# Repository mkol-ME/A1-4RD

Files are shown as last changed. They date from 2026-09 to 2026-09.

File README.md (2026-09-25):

# A1-4RD — "Alfred"




A 3D-printed desk companion with a moving jaw and a voice, written in the manner of an old-fashioned
butler: dry, warm, terse, and genuinely useful. Not a smart speaker.

Everything runs locally. A laptop (later a Raspberry Pi inside the printed body) is the face: microphone,
speaker, wake word. A headless Ubuntu box on the LAN is the brain: speech recognition, memory, web lookup,
the language model and his voice. Nothing is sent to a hosted service.

> **The character is the project. Everything else is plumbing.**

## What I built, and what I learned

I built a voice assistant with a fixed personality that runs entirely on my own hardware: speech detection
and wake word on a laptop, and Whisper, a 26-billion-parameter language model, long-term memory, web and
weather lookup and a custom synthesized voice on a home server. That server runs on a secondhand datacenter
GPU I had to reflash and coax into a consumer motherboard. Through measurement rather than guesswork, I got
a spoken reply's first sound down to about 1.15 seconds, and a web-searched answer from 7.1 to 3.5 seconds.
The biggest lesson was that intuition is unreliable with language models. Adding rules to the prompt made
the character worse three separate times. My first test suite passed while the real failures went
undetected, because its questions had leaked into the training examples. Two confident theories about why
he rambled both turned out wrong. So I built a held-out evaluation that checks its own contamination, and
changed things only when a number moved. I also learned to put boundaries in code rather than instructions:
anything that reaches the prompt will eventually be said out loud, so access to memory has to be enforced in
the database query itself.

## The physical build

The body is fully modelled in CAD; it has not been printed or assembled yet.

<p align="center">
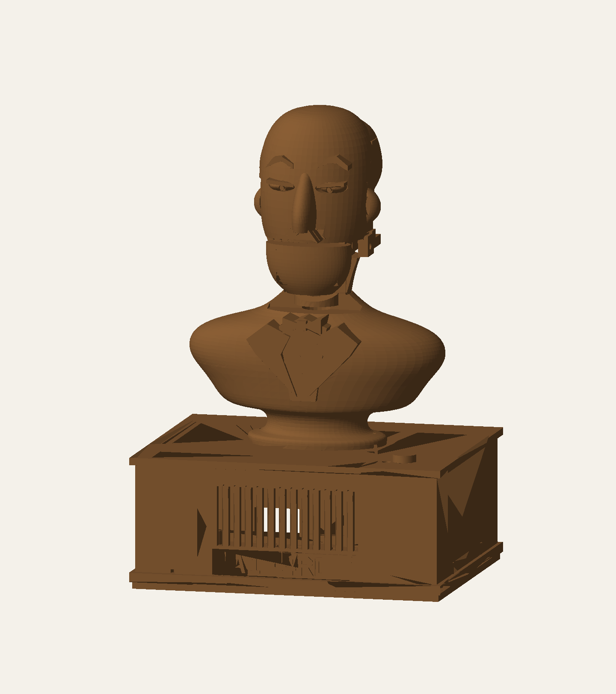
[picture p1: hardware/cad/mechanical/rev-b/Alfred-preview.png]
Rendered CAD model of the Alfred bust on its speaker plinth
  
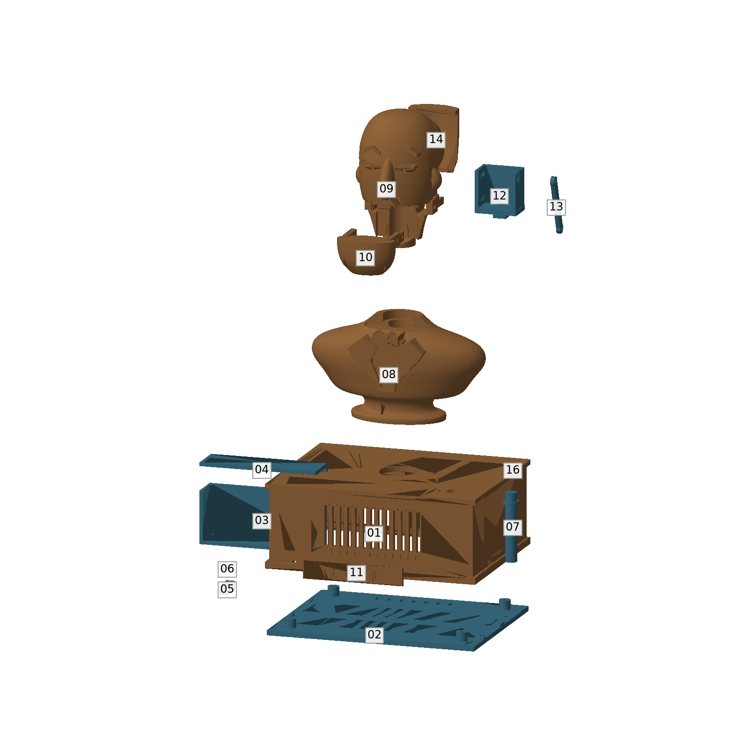
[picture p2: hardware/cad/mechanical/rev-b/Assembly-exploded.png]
Exploded view of the sixteen printed parts
  
</p>

- **Printed body** ([`hardware/cad/mechanical/rev-b`](hardware/cad/mechanical/rev-b)): sixteen parts as STEP
  solids and millimetre STL, 202 mm tall. The chin is a separate part, driven by a servo through a drive
  link, so the jaw can move while he speaks.
- **Electronics layout** ([`hardware/cad/mechanical/modules-rev-a`](hardware/cad/mechanical/modules-rev-a)):
  a tray and fit models for off-the-shelf boards — Raspberry Pi, I²S microphone, amplifier, servo driver and
  USB-C power.
- **Custom carrier PCB** ([`hardware/cad/pcb/rev-e`](hardware/cad/pcb/rev-e)): a four-layer KiCad board for a
  Pi Zero 2 W, an ICS-43434 microphone, a MAX98357A amplifier and the jaw servo, with a latching power-fault
  cutoff. Gerbers, drill files, BOM and DRC/ERC reports are included; revisions C to E are kept. Not yet
  fabricated.

The STEP files open in SolidWorks, Fusion or FreeCAD. [`hardware/cad/README.md`](hardware/cad/README.md) maps
every revision.

---

## Contents

- [The physical build](#the-physical-build)
- [How a spoken turn works](#how-a-spoken-turn-works)
- [Hardware](#hardware)
- [Repository layout](#repository-layout)
- [Talking to Alfred](#talking-to-alfred)
- [The server](#the-server)
- [Performance](#performance)
- [Testing](#testing)
- [Status and roadmap](#status-and-roadmap)
- [Further reading](#further-reading)

---

## How a spoken turn works

```text
 LAPTOP (client/)                               SERVER (brain/, over an SSH tunnel)
 ─────────────────                              ───────────────────────────────────────────────
 microphone, 16 kHz
   → speech detection against the room's
     measured noise floor
   → at 0.20 s of silence, send audio ────────→ Whisper small.en on the GTX 1060
   → at 0.40 s, end the turn — or wait up to
     1.0 s if the words so far trail off
   → wake word / attention window
   → text ────────────────────────────────────→ voice server
                                                  → tool gate: does this need a lookup?
                                                  → decider: search memory / search web
                                                    (SearXNG, Wikipedia) / sports scores
                                                    (ESPN) / news (Google News) / remember
                                                    weather goes to Open-Meteo instead
                                                  → gemma4 26B on the MI50 via Ollama
                                                  → cut the stream into whole sentences
                                                  → Alfred's distilled Piper voice (CPU)
 speaker (WASAPI) ←──── one WAV per sentence ─── ← streamed as NDJSON
```

The pieces are deliberately separable:

| Layer | Files | Decides |
|---|---|---|
| **Character** | `persona/` (private; `.example` stand-ins here), `brain/prompts.py` | how he behaves |
| **Knowledge** | `brain/memory.py`, `brain/memory_tools.py`, `brain/web.py`, `brain/weather.py`, `brain/sports.py`, `brain/news.py`, `brain/markets.py` | what evidence he sees |
| **Transport** | `brain/voice_server.py`, `brain/whisper_server.py`, SSH | how text and audio move |
| **Embodiment** | `client/listen.py`, `client/talk.py`, later the servos | how he is present in the room |

A better voice cannot fix a bad answer, and a longer prompt cannot replace memory, so each layer is
debugged on its own.

---

## Hardware

**Server** (headless Ubuntu 24.04; setup and operation in [docs/server.md](docs/server.md))

| Part | Role |
|---|---|
| i7-8700 · 48 GB DDR4 · MSI MPG Z390 Gaming Plus | host |
| **AMD Radeon Instinct MI50 32 GB** | the language model (Ollama, Vulkan backend) |
| **NVIDIA GTX 1060 6 GB** | Whisper |
| 500 GB NVMe · 3×2 TB RAID 5 · 1.5 TB | OS and models · Alfred's memory database · spare |

The MI50 is a secondhand datacenter card. Getting it working in a consumer board took a VBIOS reflash,
*Above 4G Decoding* in the BIOS and `pci=realloc` on the kernel command line. It has no fan of its own, so a
server fan is driven from the card's temperature by [`ops/fan`](ops/fan). Two driver settings keep the whole
model in video memory; without them half of it silently spilled into system RAM, at 4 tokens a second
instead of 40 ([why each setting is there](docs/server.md#ollama-settings)).

**Client:** any Windows laptop with a microphone. Later: a Raspberry Pi in the printed body, with a servo jaw
and a neck servo — see [The physical build](#the-physical-build).

---

## Repository layout

```text
A1-4RD/
├── brain/                    runs on the server
│   ├── alfred.py             model choice, prompt assembly, streaming; also a terminal chat client
│   ├── memory.py             SQLite memory: recent conversation, facts, semantic search
│   ├── memory_tools.py       the tool decider and its tools (memory, web, facts)
│   ├── web.py                Wikipedia + SearXNG lookup, run concurrently
│   ├── sports.py             live scores, results and fixtures from ESPN
│   ├── news.py               headlines from Google News
│   ├── markets.py            live prediction-market odds from Polymarket
│   ├── machine.py            the server's own temperatures, fan, power, VRAM, RAID and disks
│   ├── weather.py            live forecast from Open-Meteo, not search snippets
│   ├── media.py              "play…" / "find videos of…" requests and spoken titles
│   ├── media_server.py       YouTube search, audio stream, chapters and captions (own venv: yt-dlp, PyAV)
│   ├── guru.py               The MMA Guru's take on a fight, from his breakdown videos
│   ├── voice_server.py       one spoken turn end to end, streamed sentence by sentence
│   ├── whisper_server.py     resident Whisper, so no model load per utterance
│   ├── audio_archive.py      every utterance kept on the array with its transcript, under a size cap
│   ├── youtube.py            what a named YouTube channel has posted, from its real upload list
│   ├── spoken.py             text rules for what is said aloud, such as which voice reads a sentence
│   ├── prompts.py            loads the private wording, or the .example stand-ins
│   └── whisper_transcribe.py one-off file transcription
├── persona/
│   ├── alfred.example.md     stand-in for alfred.md (who he is), which is kept private
│   ├── examples.example.md   stand-in for examples.md (how he talks)
│   └── prompts.example.json  stand-in for prompts.json (the instructions sent with each turn)
├── client/                   runs on the laptop
│   ├── listen.py             speak to him: wake word, attention window, early transcription
│   ├── talk.py               type to him, hear him answer; also the audio player
│   ├── music.py              plays YouTube audio; pause, stop, volume, ducking under his voice
│   └── launcher/             builds Alfred.exe, a double-click launcher
├── scripts/                  server launch scripts, and a scratch copy of the voice server for testing
├── voice-training/           how his voice was made: auditions, RVC, distillation into Piper
├── tests/                    unit tests for memory, tool gate and the listening loop
├── ops/                      server setup, version-controlled
│   ├── fan/                  MI50 fan curve service + interactive installer
│   ├── reboot/               idle-only 3 a.m. reboot every third night
│   ├── ollama/               Ollama settings and boot-time model preload
│   ├── services/             start SearXNG, Whisper and the voice server at boot
│   └── remote-access/        key-only SSH and Tailscale
├── requirements/             pinned environments (client TTS, Whisper, RVC, Qwen-TTS)
├── hardware/                 CAD (STEP/STL), KiCad PCB and bring-up notes for the body
└── docs/                     running the server, and reaching it
```

---

## Talking to Alfred

- Say **"Alfred, …"** to start. He then stays attentive for three minutes without needing his name.
  **"That'll be all"** dismisses him.
- Say his name while he is talking and he stops, so you can cut in.
- **"Play …"** asks whether you want Spotify or YouTube, then plays it through his speaker. **"Find videos
  of …"** reads out the top results. While music plays, **"Alfred, pause / resume / stop / louder / quieter"** works, and the
  music drops whenever he talks.
- Ask about the weather, last night's game, the news, or something you told him last week. He decides
  on his own when a question needs a lookup.
- Typing works too: the same conversation and memory, without the audio.

Running the client and the server is covered in [docs/server.md](docs/server.md).

---

## Performance

Measured 2026-09-16, from the end of speech to Alfred's first sound, with real audio through the whole
pipeline:

| Turn | Before the MI50 work | Now |
|---|---|---|
| Plain conversation ("why do my prints warp") | 1.5 s | **≈ 1.15 s** |
| Needs the tool decider ("what should I have for dinner") | 4.2 s | **≈ 1.6 s** |
| Memory lookup ("what did I tell you about…") | 4.5 s | **≈ 1.9 s** |
| Web search, real answer (holding line at ≈ 1.0 s) | 7.1 s | **≈ 3.5 s** |

**Model choice.** Candidates run on the MI50 with Alfred's real prompt:

| Model | First sentence | Speed | Character eval |
|---|---|---|---|
| **gemma4:26b Q8** (in use) | **0.43 s** | 41 tok/s | **75/78** |
| gemma4:31b | 1.61 s | 15 tok/s | 77/78 |
| qwen3.6:35b-a3b | 1.35 s | 54 tok/s | 75/78 |
| qwen3.8:27b | 5.50 s | 17 tok/s | — |
| qwen3.5:9b (previous) | 1.77 s | 63 tok/s | 67/78 |

The Qwen 3.x models re-read the whole persona on every turn; Gemma reuses the cached prefix, which is most of
the gap. `gemma4:31b` is the alternative if character ever matters more than speed — one line in
`brain/alfred.py`.

---

## Testing

The unit tests cover memory, the tool gate, the listening loop (segmentation, wake word, unfinished
sentences), the spoken-reply rules, the voice EQ and each lookup's parsing. They need no GPU or model, and
[run on every push](https://github.com/mkol-ME/A1-4RD/actions/workflows/tests.yml):

```bash
pip install numpy scipy sounddevice
python -m unittest discover -s tests
```

The character, conversation and routing evaluations are built on the private persona and real
conversations, so they are kept out of this repository along with it.

---

## Status and roadmap

**Done**
- The persona, and the full voice pipeline: ears, memory, lookups, voice
- MI50 bring-up and latency work; services that start at boot; remote access over Tailscale
- Live weather, sports, news and web search; spoken corrections
- Music from YouTube or Spotify, ducked under his voice; cutting in by saying his name
- A typed client sharing the same conversation and memory
- Optional tools loaded from outside the repository, which can report back when a long job finishes
- The printed body and the carrier PCB, designed in CAD

**Next**
- Recognising who is speaking, with separate memory per person (enforced in SQL, never in the prompt)
- Small character faults — through example curation, not more rules
- A bench prototype of the electronics ([plan](hardware/bringup-plan.md))

**Later:** the Raspberry Pi client inside the printed body, with the servo jaw and neck; timers and alarms
that still ring when the network is down.

---

## Further reading

- [docs/server.md](docs/server.md) — running the client and the server
- [docs/SSH.md](docs/SSH.md) — reaching the server
- [hardware/](hardware) — the physical build

## License

The code is released under the [MIT License](LICENSE). The Adafruit board files in
[`hardware/cad/mechanical/modules-rev-a/source/board-sources`](hardware/cad/mechanical/modules-rev-a/source/board-sources)
keep their own CC BY-SA licence.

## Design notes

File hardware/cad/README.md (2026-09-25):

# Alfred CAD archive

These are the complete generated CAD deliverable folders for the Alfred physical prototype. Each revision is kept intact so its own README, checks, source files, and exports stay together. They are **design snapshots**, not proof of a built or qualified device.

| Folder | Contents | Status |
| --- | --- | --- |
| `mechanical/rev-a/` | Initial bust and enclosure; STEP, STL | Superseded by rev B |
| `mechanical/rev-b/` | Revised bust, jaw, enclosure; STEP, STL | Latest exterior baseline |
| `mechanical/module-fit-review/` | Fit review and next steps | Reference notes |
| `mechanical/modules-rev-a/` | Revised tray and fit models for off-the-shelf Pi/audio/power modules; STEP, STL, CadQuery source | Latest module-based prototype geometry; use with the rev B exterior parts named in its README |
| `pcb/rev-c/` | KiCad carrier project and fabrication exports | Superseded by rev D |
| `pcb/rev-d/` | KiCad carrier project and fabrication exports | Superseded by rev E |
| `pcb/rev-e/` | KiCad carrier project and fabrication exports | Latest custom-PCB candidate; unbuilt and purchasing deferred |

## Starting points

- For the printed body and currently proposed breakout-module prototype, start with `mechanical/rev-b/README.md` and `mechanical/modules-rev-a/README.md`.
- For the custom PCB design, start with `pcb/rev-e/README.md` and its power-acceptance and validation notes. Do not send its Gerbers for fabrication without the remaining physical checks.
- The repository's `hardware/v1-electronics-bom.pdf` is a separate early bench-shopping list. It is not a purchasing BOM for the module package or PCB rev E.

Large STEP and STL files are stored with Git LFS. The native SolidWorks files are kept offline; the STEP exports open in SolidWorks. Clone with Git LFS enabled to receive the actual models rather than pointer files.

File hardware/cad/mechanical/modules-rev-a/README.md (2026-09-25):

# Alfred — module prototype A

13 September 2026. A mechanical layout and fit-test package for the Pi Zero 2 W / local-server architecture. **Bench qualification remains required; this is not a tested appliance or a PCB fabrication release.**

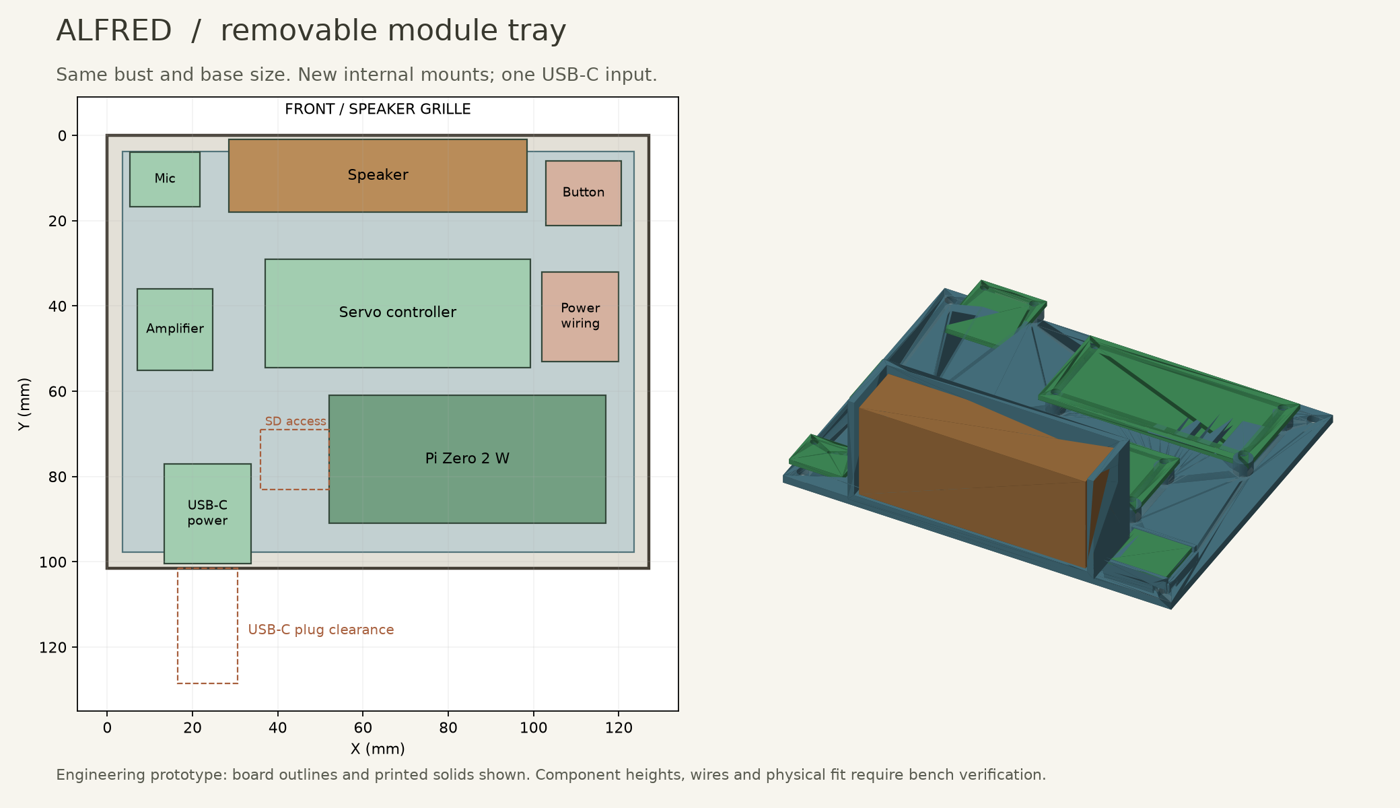
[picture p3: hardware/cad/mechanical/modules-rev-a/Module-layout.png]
Module layout


## What changed

The finished bust exterior, overall size and existing jaw linkage are retained. The custom carrier PCB is replaced by an assembled microphone board, amplifier board, servo pulse controller and USB-C power-input board on a printed tray. A small hand-wired power distribution assembly and button perfboard are still required. Some header and wire soldering is unavoidable.

New or revised printed parts:

| File in CAD/ | Change |
|---|---|
| 01_Plinth_modules | Existing rear power opening extended left to X=15.5 and upward to Z=21.5. Front and overall envelope unchanged. |
| 03_Speaker_mount_modules | Adds a lead clearance notch behind the speaker. |
| 07_Button_stem_modules | Shortens the lower end to Z=22.1 for a switch actuator at Z=21.9. |
| 17_Electronics_tray | Uses the four existing base supports; separate board mounts and microphone acoustic extension. |
| 18_Switch_carrier | Supports a 17.78 x 15.24 x 1.6 mm piece of perfboard beneath the original button. |

Unchanged parts are included as STEP/STL. The original SolidWorks files are kept offline, unchanged; Revision B's STEP exports carry the same geometry. New parts are STEP solids, printable STL and regenerable Python/CadQuery geometry, **not native SolidWorks feature trees**. Import the assembly STEP into SolidWorks for inspection or further work. Reference envelopes are named separately and must not be printed as hardware.

## Selected electronics

| Qty | Item | Purpose / constraint |
|---:|---|---|
| 1 | Raspberry Pi Zero 2 W | Existing Python/SSH audio client. Use a header fitted on the component side. |
| 1 | Adafruit 6049, ICS-43434 breakout | Microphone; bottom acoustic port faces the printed duct. |
| 1 | Adafruit 3006, MAX98357A mono amplifier | Drives the enclosed speaker. |
| 1 | Adafruit 815, PCA9685 servo controller | Produces stable servo pulses independently of Linux scheduling. PCB Rev C source used for mounting. |
| 1 | Adafruit 5807, HUSB238 power breakout | One USB-C input, fixed **5 V / 3 A request**. See Wiring.md before connecting. |
| 1 | Raspberry Pi official 27 W USB-C supply, appropriate regional version | Previously selected supply; validate its actual 5 V contract and loaded output with the HUSB238. Do not infer 5 A operation from the supply label. |
| 1 | Adafruit 3351, enclosed 4-ohm 3 W speaker | Nominal body fits the existing cradle; verify actual lead exit and tabs. |
| 1 | FEETECH FS90 positional servo | Original jaw mechanism. FS90R continuous-rotation is unsuitable. |
| 1 | Omron B3F-1000 momentary switch | On separate perfboard, centered under the existing button. |
| 1 each | Littelfuse 025102.5MXL and 02511.25MXL | 2.5 A Pi/audio branch fuse and 1.25 A motor branch fuse; verify startup/inrush on bench. |
| 1 | 470–1000 uF, 10 V radial electrolytic, body at most 8 mm diameter x 20 mm high | At PCA9685 V+ / GND capacitor footprint; observe polarity. Capacity is a bench starting value, not proof of transient immunity. |
| 1 each | 1 kohm and 10 kohm resistors, 0.125 W or greater | OE pull-up and amplifier SD pull-down. |
| 1 | 10 kohm resistor | Button pull-up to 3.3 V. |
| 1 | 32 GB or larger microSD and reader | Lite OS, client software and configuration. |
| As needed | Perfboard, 22 AWG stranded power wire, 26–28 AWG signal wire, 2.54 mm headers/shunt, heat-shrink, connectors, strain relief | See Wiring.md. No powered breadboard rails for the motor branch. |

The parts above define the design, not a current shopping cart. Price/availability and exact cable/header SKUs will be checked in the purchasing step. The controller adds cost but avoids a servo software-timing problem and preserves future channels. No extra computer is needed inside Alfred.

## Assembly sequence

1. Print the existing fit coupon (15) first. Use it for bores and a servo body trial. Then trial-print the new tray, switch carrier and shortened stem in ordinary PETG before cosmetic filament.
2. Check the real servo before committing to the head assembly. The old cradle has an approximately 22.6 mm clear width between rails, while the supplier gives dimensions up to 23.2 mm body length and 23 mm case/gear height in its drawing. Orientation matters. The old CAD does not conclusively establish the shaft position with the real servo and horn. Do not force it or file the servo case; adjust the cradle after a measured fit. The servo axis must remain parallel to X at Y=58, Z=176 for the existing link.
3. Place the unchanged duct and lid on the bottom cover. Fit the tray at Z=9 using four M3 screws. M3 x 8 is a starting length; washer/head stack and screw penetration must be checked. The modeled screw-head envelope is diameter 6.2 x 2.5 mm above tray top. Use heads within that envelope.
4. Seal the tray's acoustic bore to the existing duct lid with a thin perimeter seal. Fit a compressible annular gasket into the 0.2 mm recess at the top of the microphone riser. Its central opening must remain clear. Mic board underside is Z=16. Clip solder tails below the microphone header to at most 1.5 mm and inspect clearance over the nearby M3 head.
5. Install board fasteners with insulating washers. Tray holes are 2.2 mm: use M2 screws and nuts, including for the Pi's larger holes. Mic/Pi/amp/PCA seat Z=16; power board seat Z=14.5. M2 x 12 for the former and M2 x 10 for power are starting lengths. Fit nuts before placing the tray where access would become difficult; test screw tip clearance above the floor.
6. Fit the switch centered at X=111.75,Y=13.55 on the small perfboard, with board underside Z=16. Carrier side rails support the board; retain with removable tape at its edges. Attach the carrier feet to the tray after fitting tray screws. Verify 0.2 mm initial actuator gap and free return before bonding the cap.
7. Fit the speaker with thin foam. Orient the cable through the revised notch. The listed speaker nominal envelope leaves 2 mm total slack in each pocket dimension before padding. Retain the original lid with a light strap or removable tape.
8. Secure the insulated power harness in the reserved X=102..120,Y=32..53,Z=13..37 volume. Keep solder joints off printed plastic using insulating supports. Secure wiring with adhesive cable anchors; no loose assemblies in the cavity. Keep the Pi's antenna end and ventilation free of wire bundles.
9. Bench-test before closing the base. The Pi SD card is serviced by removing the bottom module; the former rear SD opening remains a vent/service opening, not an aligned card slot. The new power module is screwed down near the rear opening; confirm the actual USB-C plug fits the modeled 14 x 6 mm section and can fully seat.
10. Route the servo cable through the torso with a service loop behind the moving jaw. Retain the existing jaw pivot, 35.114 mm link and 8 mm horn radius. Begin calibration with the link detached. Attach only after real closed/open pulse limits have been established.

## What the checks establish

The package includes fresh STL integrity checks and BRep intersection checks of the printed assembly against module board outlines, component/service envelopes and tray screw heads. The envelopes reserve space; they are not certified manufacturer 3D models. Wires can bend outside their nominal reserved spaces unless secured.

**The actual servo, horn, cable deformation, print shrinkage, thermal behavior, acoustics and power transients are not validated by these checks.** Existing jaw-motion results remain a printed-geometry-only reference. No physical Pi has been booted or measured in this task.

Compared with the custom PCB, this prototype has basic branch fuses and servo output disabling; it does **not** reproduce the PCB's undervoltage latch, active inrush limiting or regeneration clamp. It is for supervised bring-up. Measure the power behavior before extended assembled use; a fuse alone does not stop a stalled servo promptly or prevent a brownout.

See Wiring.md for connections and Bring-up.md for test order. Custom PCB Rev E remains unfinished and should not be ordered.

## Sources

- [Raspberry Pi Zero 2 W](https://www.raspberrypi.com/products/raspberry-pi-zero-2-w/)
- [Microphone PCB files](https://github.com/adafruit/Adafruit-I2S-MEMS-Microphone-Breakout-PCB)
- [Amplifier PCB files](https://github.com/adafruit/Adafruit-MAX98357-I2S-Amp-Breakout)
- [Servo-controller PCB files](https://github.com/adafruit/Adafruit-16-Channel-PWM-Servo-Driver-PCB)
- [Power-module PCB files](https://github.com/adafruit/Adafruit-USB-Type-C-Power-Delivery-Dummy-Breakout-PCB)
- [HUSB238 jumper instructions](https://learn.adafruit.com/adafruit-husb238-usb-type-c-power-delivery-breakout/pinouts)
- [Speaker dimensions](https://www.adafruit.com/product/3351)
- [FS90 supplier drawing](https://www.pololu.com/file/0J1435/FS90-specs.pdf)
- [Littelfuse 251 datasheet](https://www.littelfuse.com/assetdocs/littelfuse-fuse-251-253-datasheet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)

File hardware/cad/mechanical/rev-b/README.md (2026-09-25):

# A1-4RD / Alfred — printable prototype, revision B

STEP parts and a reference assembly, plus millimetre STL exports. The native SolidWorks files are kept offline.
Designed from alfred.jpg and the routed carrier PCB mechanical interface from the earlier task.
The face has solid eyeballs, iris relief, pupils, half-lowered lids, eyebrows, a long nose, ears and a moustache. The chin is a separate moving part. This is a stylized CAD interpretation of the reference, not a scanned likeness.

## Scale and coordinates

Overall nominal height 202 mm (7.95 inches), including base. Plinth footprint 137 x 111.6 mm, with a small additional projection at the front lettering. Main base wall 3 mm. Internal chamber 127 x 101.6 x 50.8 mm, measured above the floor at global Z=3 mm. Global X goes right, Y goes back, Z goes up. Internal front-left floor corner is (0,0,3).

Carrier PCB 120 x 94 x 1.6 mm. PCB front-left XY=(3.5,3.8). Underside Z=9, top Z=10.6. Four M3 pilot supports at (7.5,7.8), (119.5,7.8), (7.5,93.8), (119.5,93.8). Pi support hardware remains M2.5 and mounts on the PCB, not the enclosure floor.

The PCB, Pi, commercial servo, servo horn, speaker and fasteners are NOT included as detailed component models. Purchased-part compatibility is based on the preceding PCB interface and listed nominal dimensions. Measure the actual header stack, switch, servo shaft location and speaker before the final print.

## Files and parts

| Part | Material | Assembly / print note |
|---|---|---|
| 01_Plinth | Bronze PLA | Speaker front, USB/SD rear; print top face on bed, cavity upward, inspect supports around grille |
| 02_Bottom_cover | PETG | PCB supports; print floor on bed |
| 03_Speaker_mount | PETG | Padded 72 x 19 x 32 mm pocket; bond to inner front wall at model position; no supports through PCB |
| 04_Speaker_lid | PETG | Removable roof; retain with removable tape or a light strap |
| 05_Microphone_duct | PETG | Print open channel upward, clean bore, bond to bottom cover |
| 06_Microphone_duct_lid | PETG | 0.5 mm roof; use 0.1 mm layers; 0.2 mm thin gasket seat around PCB mic bore |
| 07_Button_stem | PETG | Insert from underneath BEFORE bonding cap |
| 08_Torso | Bronze PLA | Hollow wiring space, jacket and bow tie; support as needed; M3 attachment from inside plinth |
| 09_Alfred_head | Bronze PLA | Solid eyes and face; rear service opening; print with supports kept away from eye details where possible |
| 10_Moving_jaw | Bronze PLA or PETG | Separate chin, axle cheeks and rearward drive arm; ream bores |
| 11_Name_plaque | Bronze PLA | A1-4RD lettering raised 0.8 mm; place flat back on bed; bond to front |
| 12_Servo_cradle | PETG | Strap mounting with an M2 base screw; confirm actual FS90 body/shaft position |
| 13_Drive_link | PETG | Print flat; 35.114 mm pivot-center distance; M2 clearances |
| 14_Rear_cover | Bronze PLA | Removable prototype cover; retain with narrow removable tape around rear seam |
| 15_Fit_coupon | PETG | First print: servo body sample and 3.2 mm bores |
| 16_Button_cap | Bronze PLA | Bond onto installed stem; keep glue out of guide |

Use one of each. Assembly contains the 15 installed printed components; the coupon is separate. The assembly is a fixed positional reference, not a mated motion simulation. The linkage is positioned at the closed-jaw reference.

All part files share assembly coordinates. In Bambu Studio import individual STLs as separate objects and use Lay on Face / Drop to Bed; do not print their floating assembly Z coordinates. No printer-specific G-code is supplied.

## Jaw mechanism

Use a 3 mm metal axle, approximately 50 mm long, trimmed to the actual head width and retained at both ends. Printed main axle bores are 3.2 mm in the head and 3.3 mm in the jaw. Ream to a free-running fit; do not force a screw thread through a bearing surface.

Reference jaw pivot: (Y,Z)=(52,143). The jaw drive point is 10 mm behind the pivot, at (62,143) when closed. Reference servo shaft: (58,176), axis parallel to X. Use an 8 mm horn radius and the 35.114 mm link. The rod occupies X=79.5..81.9. Use M2 screws, washers/spacers and locknuts to maintain free pivots. Keep the supplied servo spline/horn; no printed spline is provided.

| Jaw opening | Reference crank angle |
|---:|---:|
| 0 degrees | 180.000 degrees |
| 5 | 173.513 |
| 10 | 166.483 |
| 15 | 158.776 |
| 20 | 150.181 |

These are geometric angles in the YZ plane, NOT servo PWM commands. Calibrate the horn's center and actual shaft position before connecting the linkage. The bracket allows strap mounting rather than relying on unverified tab holes. If the purchased shaft cannot be placed at the reference coordinate, modify the bracket/link before operation. Start with a small travel range and limit normal operation to 0..20 degrees. Do not drive the servo into a stop.

The head includes a BRep clearance feature calculated from sampled jaw positions and a 2% enlargement of the jaw around its pivot. Earlier sketches/features remain in the native file, but this final clearance body does not automatically regenerate from upstream changes: recalculate it after changing jaw geometry or pivot placement.

## Hardware and fit

- Four M3 screws for the PCB, four M3 screws through the bottom cover, and two M3 screws from inside the base into the torso. Pilot holes are 2.6 mm; verify self-tapping fit on scrap. Select lengths to avoid bottoming or piercing the shell; PCB screws typically M3 x 6 with insulating washers, cover M3 x 8, torso M3 x 8 subject to washer thickness.
- Head has a 20 mm spigot and torso a 20.6 mm socket. Lightly bond after wiring/fit confirmation; rear cover permits servo access.
- Servo cradle uses an M2 screw into a 1.7 mm pilot, with a recessed head, and narrow cable ties through the rail slots.
- Speaker: Adafruit 4445 nominal 70 x 31 x 17 mm enclosed body, padded with thin foam. Mounting is by cradle, not its unverified screw pattern. Keep factory enclosure intact.
- The microphone duct must be sealed to the PCB underside around its 0.5 mm acoustic bore. Use a thin compressible gasket; keep adhesive, dust and filament out of the acoustic path.
- Button stem is based on a nominal 4.3 mm switch height above PCB top: 0.2 mm initial clearance and about 0.45 mm cap travel. Verify the actual B3F-1000 actuator height/travel and adjust stem length before bonding cap.
- Keep the Pi antenna area free of metal hardware and cable bundles. Provide a service loop in the neck.
- Rear USB opening: global X 23.5..43.5, Z 6.5..18.5. SD access: X 81.5..115.5, Z 19.5..31. Allow cable and card withdrawal space behind the figure.

## Bambu P1 print starting point

Use a 0.4 mm nozzle. Start with the appropriate Generic PLA / Generic PETG profile, then tune to the filament manufacturer. Decorative head and jaw: 0.12–0.16 mm layers; base/torso: 0.20 mm; 4 walls and 15–20% infill as a starting point. Mechanism: 4–5 walls; link 100% infill. Slow outer walls for the face and lettering. Inspect support contact and bore cleanup in the slicer. The thin microphone lid should be printed separately at 0.1 mm layers.

Bronze PLA is appropriate for the cosmetic shell; PETG is preferred for internal supports. Validate enclosure temperature with the real electronics running before long unattended use. ABS is unnecessary for this first prototype.

## Filament sourcing — checked 6 September 2026

1. [Polymaker Panchroma Metallic Bronze PLA, 1.75 mm, 1 kg](https://shop.polymaker.com/products/metallic-pla?variant=43595097407545): $24.99, selected Bronze variant available when checked. Manufacturer calls for at least a 0.4 mm nozzle, 190–230 C nozzle and 25–60 C bed. Bronze appearance comes from a decorative metallic effect; no plating needed.
2. [Polymaker PETG, Black / New Formula, 1.75 mm, 1 kg](https://shop.polymaker.com/products/petg?variant=45079221108793): $18.99, selected variant available when checked.

Two-spool subtotal $43.98 before tax/shipping; no purchase has been made. One bronze spool and one PETG spool are a practical starting purchase including test prints. If you already have PETG, buy only bronze. Availability can change.

Material references: [Polymaker metallic PLA](https://shop.polymaker.com/products/metallic-pla), [Prusa PETG guide](https://help.prusa3d.com/article/petg_2059), [FS90 specifications](https://www.pololu.com/product/2818/specs).

## Release status

This is an unbuilt prototype. Geometric checks cover the modeled printed parts; they do not establish purchased hardware fit, print tolerance, acoustic performance, motor calibration or thermal performance. See the validation JSON files for exact checks performed. Print the coupon and mechanism first, then the cosmetic pieces.

## Reinforced head and assembly guide

The final head has connected 4 mm side rails, upper/lower crossmembers, reinforced axle bearings and a thicker rear neck root. Use six walls on the head. See Alfred-assembly-guide.pdf for the exploded schematic, linkage dimensions and numbered assembly instructions.

Validation: all 16 STL meshes checked for watertightness, winding and connected components (mesh-validation.json); all native part bodies passed kernel checks. No static printed-part interferences were detected. Jaw/link motion was sampled at each integer degree from 0 through 20 against the modeled head, torso, cradle and rear cover; no collisions were detected at those samples. Purchased components were not included in that clearance check.

## Revision B: classical bust silhouette and BTAS facial details

The torso now has broad upper shoulders, a tapered chest and an integral short oval socle inspired by the supplied classical bust photograph. Alfred retains a formal shirt, pointed tuxedo lapels, bow tie and shirt studs. The original head/socket position, 202 mm overall height, base attachment and PCB enclosure dimensions are preserved. The torso includes a continuous 18 x 16 mm wiring passage through the pedestal.

The head revision trims the long ears into compact lobed ears with shallow inner recesses, adds raised receding side-hair volumes, and sharpens the pointed moustache. The bald crown, solid eyes and reinforced jaw frame remain. These facial features are integral prints.

Reference: original user Alfred BTAS image, supplemented by [The World's Finest Alfred reference gallery](https://dcanimated.com/batribute/batribute-characters/batribute-characters-alfred-index2/).

The new torso has a front-neck relief for the moving chin. The rear neck and socket floor retain the head support; route and secure the neck service loop behind the moving chin.

## Reinforced head and assembly guide

The final head has connected 4 mm side rails, upper/lower crossmembers, reinforced axle bearings and a thicker rear neck root. Use six walls on the head. See Alfred-assembly-guide.pdf for the exploded schematic, linkage dimensions and numbered assembly instructions.

Validation: all 16 STL meshes checked for watertightness, winding and connected components (mesh-validation.json); all native part bodies passed kernel checks. No static printed-part interferences were detected. Jaw/link motion was sampled at each integer degree from 0 through 20 against the modeled head, torso, cradle and rear cover; no collisions were detected at those samples. Purchased components were not included in that clearance check.

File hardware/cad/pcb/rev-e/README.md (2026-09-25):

# Alfred carrier - revision E

Native KiCad 10 project for Pi Zero 2 W, ICS-43434 microphone, MAX98357A amplifier and one FS90 servo. Revision E replaces D for the next prototype evaluation. Purchasing is deferred.

- R107: verified 32.0k 0.1% part, with recalculated supervisor thresholds.
- R101: Pi/audio current limit lowered from about3.33A to2.02A nominal.
- C101:10nF; slower Pi/audio startup reduces nominal reservoir charging surge from0.94A to0.44A.
- External requirements now include the Pi, microSD, stencil/assembly and enclosure/linkage.

The supported design target is <=1.65A Pi/audio and <=0.80A servo; the earlier4.1A operating allocation is withdrawn. This is a deliberate reduction in supported load, not proof that all power-margin concerns are resolved. Read Power-acceptance.md. It includes source-voltage/path-loss criteria and tests that still require built hardware. The hardware latch still prevents restart after a detected fault until a deliberate new command edge.

Open Alfred.kicad_pro. Use the current BOM, Gerbers, assembly instructions and drawings together. Validation.txt records the completed CAD and offline checks. No physical board or target audio software has been tested; prototype power qualification is still open. Do not describe this release as production-qualified.

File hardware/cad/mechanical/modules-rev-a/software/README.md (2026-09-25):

# Pi client hardware setup — module prototype A

The server continues to perform transcription, language generation and voice synthesis. No server model changes are needed.

The supplied audio overlay and smoke test are adapted from the previous hardware package. They target the Raspberry Pi voiceHAT codec/machine interface at 48 kHz, stereo, signed 32-bit little-endian audio. **The overlay has not been compiled or boot-tested on a physical Pi in this task.** Verify the installed kernel provides the required drivers and symbols.

1. Install Raspberry Pi OS Lite. Install `device-tree-compiler` and `alsa-utils` using its package manager.
2. Confirm the kernel has `snd_soc_googlevoicehat_codec` and `snd_soc_rpi_simple_soundcard`, either modules or built in.
3. Run `sh build-overlay.sh`. If successful, copy `alfred-audio.dtbo` into the active boot overlays directory, normally `/boot/firmware/overlays/`. Back up the boot configuration before editing it.
4. Use this configuration, removing conflicting audio overlays:

```ini
dtparam=audio=off
dtparam=i2c_arm=on
dtoverlay=alfred-audio
gpio=22=op,dh
```

GPIO17 is owned by the audio driver for amplifier SD. GPIO22 is PCA9685 OE, HIGH=disabled. Do not install the former GPIO12 PWM overlay or the former GPIO22 LOW-at-boot setting.

5. Reboot and inspect `arecord -l` and `aplay -l`. Run the smoke test using its `--help` instructions and the actual card name. It plays a quiet tone and captures the mic; listen to the recorded file and inspect logs, not just the exit code.
6. Configure the existing `listen.py`/`talk.py` audio devices. Native hardware format is 48 kHz stereo S32_LE; use tested conversion to the client's expected format. Mic data is on the left channel. Do not assume the default audio device or channel mapping is correct.
7. Add PCA9685 support using a maintained I2C library. Initialize OE HIGH, initialize at 50 Hz with unused channels off, set the actual calibrated channel-0 pulse, then enable OE. Keep the identity button on GPIO27. A completed servo integration into the Alfred client is a separate target-hardware step; this package does not silently modify the working client.

The old PCB supply-good/fault pins and hardware arm latch do not exist in this module prototype. Read ../Wiring.md before using any old servo code.

Kernel references reviewed in the prior design:

- https://raw.githubusercontent.com/raspberrypi/linux/rpi-6.12.y/sound/soc/bcm/googlevoicehat-codec.c
- https://raw.githubusercontent.com/raspberrypi/linux/rpi-6.12.y/sound/soc/bcm/rpi-simple-soundcard.c
- https://raw.githubusercontent.com/raspberrypi/linux/rpi-6.12.y/arch/arm/boot/dts/overlays/googlevoicehat-soundcard-overlay.dts

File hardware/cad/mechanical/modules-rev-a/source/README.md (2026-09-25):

# Regenerating the geometry

Install requirements.txt into a separate Python environment, then run build_module_cad.py. It uses the source STEP geometry and saved manufacturer PCB snapshots and regenerates this package's CAD, assembly, placement and clearance outputs. Back up manual changes first. New geometry is parameterized in the script; imported original parts remain STEP solids.

Manufacturer board files and attribution/license texts are retained under board-sources. Original Adafruit board designs are credited to Adafruit Industries and their respective designers; see each supplied README and license. New enclosure changes were made for the Alfred project. Reference blocks are simplified fit envelopes, not manufacturer-certified component models.

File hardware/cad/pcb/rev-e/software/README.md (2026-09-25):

# Alfred audio and jaw bring-up

This package adds a concrete audio integration path. It is **source-reviewed, not tested on a physical Alfred or compiled on this Windows host**. Use Raspberry Pi OS with the Raspberry Pi kernel and the existing voiceHAT codec/machine modules. Review was against `rpi-6.12.y`; verify compatibility for the image you install.

The voiceHAT codec supports simultaneous 48 kHz stereo S32_LE capture/playback and controls an amplifier enable GPIO. The companion machine driver selects standard I2S and derives a 64-bit frame for 32-bit samples. Those interfaces match Alfred's intended clocks and data wiring. The included overlay changes amplifier enable to **GPIO17**. Do not use the unmodified stock overlay, which drives GPIO16 instead.

## Setup on the Pi

1. Install `device-tree-compiler`, `alsa-utils` and Python 3 using the Pi's package manager. Confirm `modinfo snd_soc_googlevoicehat_codec` and `modinfo snd_soc_rpi_simple_soundcard` find the modules; built-in drivers may instead appear in the kernel configuration. If neither modules nor built-ins exist, use a supported Raspberry Pi kernel before proceeding.
2. Run `sh build-overlay.sh` in this directory. Stop if dtc reports errors. Copy the resulting `alfred-audio.dtbo` to `/boot/firmware/overlays/` (older installations use `/boot/overlays/`). Keep a backup of the boot configuration before editing it.
3. Add the following to the active boot configuration (`/boot/firmware/config.txt` on current Raspberry Pi OS):

```ini
dtparam=audio=off
dtoverlay=alfred-audio
gpio=22=op,dl
# GPIO12 uses hardware PWM0, separate from the I2S pins.
dtoverlay=pwm,pin=12,func=4
```

Remove conflicting I2S audio overlays and do not enable PWM analog audio. Reboot manually after reviewing the file. No installation or reboot is performed by the supplied build script.

4. Use `arecord -l` and `aplay -l` to identify the same voiceHAT card in both directions. Use its actual ALSA ID; do not assume it is card 0. The kernel card name contains `googlevoicehat` because the existing driver is reused.
5. With the servo disconnected and hardware voltages checked, run `python3 audio-smoke-test.py --device hw:YOUR_CARD_ID,0`. This intentionally emits a quiet test tone and records two short local WAV files. Avoid other audio clients during the test. The script refuses to overwrite its output folder; choose a new `--output` for each run.

## Application contract

- Use 48,000 Hz, two 32-bit slots, S32_LE. Expected LRCLK is 48 kHz and BCLK 3.072 MHz.
- Capture contains the microphone in the **left** channel. Extract that channel for recognition; the right channel is not a second microphone. The mic has 24 useful bits within the 32-bit slot.
- Playback also uses the **left** channel. Duplicate mono speech into both slots or explicitly place it on the left.
- Start at -12 dBFS or lower for speech and raise only after testing. Revision E's 9 dB hardware gain can approach the speaker's 3 W rating at full scale, but clean output depends on supply and load. The smoke test uses -30 dBFS.
- The kernel owns GPIO17. Do not claim it in the Alfred application at the same time.
- Add playback-reference acoustic echo cancellation for listening while speaking. Full duplex alone does not suppress the loudspeaker or servo noise.
- Test continuous capture while repeatedly starting/stopping playback, then the reverse. Run a 30-minute combined test with Wi-Fi and supervised jaw movement; log ALSA errors, `vcgencmd get_throttled`, and minimum measured Pi-header voltage.

## Jaw control contract

GPIO22 requests servo power; GPIO25 reports supply-good; GPIO27 reports active-low servo fault. GPIO12 is PWM0. Keep request low on startup and shutdown. Prepare a 50 Hz PWM waveform at a calibrated neutral pulse before requesting power. Use hardware PWM through the kernel; do not use a PCM-timed servo library while audio uses I2S.

Revision E has a hardware arm latch. First drive GPIO22 LOW. Require GPIO25 supply-good HIGH for at least 100 ms and GPIO22 LOW for at least 10 ms before a deliberate GPIO22 rising edge. A request issued while supply-good is LOW will not arm later when the rail recovers. The supervisor also applies about 107 ms nominal recovery qualification. Check the fault input after the servo rail has completed its approximately 12 ms startup ramp. Clear GPIO22 immediately if supply-good falls or a powered-servo fault appears, and require a deliberate retry. After a detected undervoltage fault, hardware remains disarmed even if GPIO22 stayed HIGH. Deliberately clear it LOW and repeat qualification only after investigating the fault. Do not auto-retry a jam in a tight loop. On application exit, clear the power request before releasing PWM/GPIO ownership.

Start with the linkage detached. A 1500 us pulse is a conventional starting point, not a guarantee of Alfred's safe jaw position. Measure and store the real closed/open limits; never assume the full 500-2500 us range is safe. No jaw movement script is included because the mechanical limits have not been supplied.

## Sources

- [Raspberry Pi voiceHAT codec](https://raw.githubusercontent.com/raspberrypi/linux/rpi-6.12.y/sound/soc/bcm/googlevoicehat-codec.c)
- [Raspberry Pi machine driver](https://raw.githubusercontent.com/raspberrypi/linux/rpi-6.12.y/sound/soc/bcm/rpi-simple-soundcard.c)
- [Raspberry Pi voiceHAT overlay](https://raw.githubusercontent.com/raspberrypi/linux/rpi-6.12.y/arch/arm/boot/dts/overlays/googlevoicehat-soundcard-overlay.dts)

The DTS uses the existing GPL kernel interfaces and carries a GPL-2.0-only identifier. It identifies the compatible interface; it does not claim Alfred is a Google-manufactured board.

## Offline logic check

Run `python3 validate-hardware-logic.py` from any directory to repeat the latch truth-table sequence checks and static threshold calculations. This reads the package design-data.json. It neither accesses GPIO nor substitutes for physical fault injection.

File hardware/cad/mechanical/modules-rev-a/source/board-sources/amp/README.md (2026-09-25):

## Adafruit MAX98357 I2S Amp Breakout PCB
<a href="http://www.adafruit.com/products/3006"><br/>
Click here to purchase one from the Adafruit shop</a>
<a href="http://www.adafruit.com/products/6513"><br/>
Click here to purchase one from the Adafruit shop</a>

The all in one digital audio amp breakout board that works incredibly well with the Raspberry Pi! If you're looking for an easy and low cost way to get you digital sound files bumpin' then the MAX98357 I2S Amp Breakout is for you. It takes standard I2S digital audio input and, not only decodes it into analog, but also amplifies it directly into a speaker. Perfect for adding compact amplified sound, it takes 2 breakouts (I2S DAC + Amp) and combines them into one.

I2S (not to be confused with I2C) in a digital sound protocol that is used on circuit boards to pass audio data around. Many high end chips and processors manage all of the audio in digital I2S format. Then, to input or output data, three or four pins are used (data in, data out, bit clock and left-right channel select). Usually, for audio devices, there's a DAC chip that will take I2S in and convert it to analog that can drive a headphone.

This small amplifier is surprisingly powerful - able to deliver 3.2 Watts of power into a 4 ohm impedance speaker (5V power @ 10% THD). Inside the miniature chip is a class D controller, able to run from 2.7V-5.5VDC. Since the amp is a class D, it's incredibly efficient - making it perfect for portable and battery-powered projects. It has built in thermal and over-current protection but we could barely tell it got hot.

PCB files for the Adafruit MAX98357 I2S Amp Breakouts
- https://www.adafruit.com/product/3006
- https://www.adafruit.com/product/6513

### License

Adafruit invests time and resources providing this open source design, please support Adafruit and open-source hardware by purchasing products from [Adafruit](https://www.adafruit.com)!

All text above must be included in any redistribution

Designed by Limor Fried/Ladyada for Adafruit Industries.
Creative Commons Attribution/Share-Alike, all text above must be included in any redistribution. 
See license.txt for additional information.

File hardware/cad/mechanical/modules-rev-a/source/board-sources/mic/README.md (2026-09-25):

## Adafruit I2S MEMS Microphone Breakout - ICS-43434 PCB

<a href="http://www.adafruit.com/products/6049"><br/>
Click here to purchase one from the Adafruit shop</a>

PCB files for the Adafruit I2S MEMS Microphone Breakout - ICS-43434. 

Format is EagleCAD schematic and board layout
* https://www.adafruit.com/product/6049

### Description

Listen to this good news - we now have a breakout board for a super tiny ICS43434 I2S MEMS microphone. Just like 'classic' electret microphones, MEMS mics can detect sound and convert it to voltage, but they're way smaller and thinner. This microphone doesn't even have analog out, it's purely digital. The I2S is a small, low-cost MEMS mic with a range of about 50Hz - 15KHz, good for all general audio recording/detection. The chip has a built in low-pass filter that cuts frequencies above 24KHz.

For many microcontrollers, adding audio input is easy with one of our analog microphone breakouts. But as you get to bigger and better microcontrollers and microcomputers, you'll find that you don't always have an analog input, or maybe you want to avoid the noise that can seep in with an analog mic system. Once you get past 8-bit micros, you will often find an I2S peripheral that can take digital audio data in! That's where this  I2S Microphone Breakout featuring the TDK ICS43434 comes in.

Instead of an analog output, there are three digital pins: Clock, Data, and Left-Right (Word Select) Clock. When connected to your microcontroller/computer, the 'I2S Controller' will drive the clock and word-select pins at a high frequency and read out the data from the microphone. No analog conversion required!

The microphone is a single mono element. You can select whether you want it on the Left or Right channel by connecting the Select pin to power or ground. If you need stereo, pick up two microphones! You can set them up to be stereo by sharing the Clock, WS, and Data lines but having one with Select to ground, and one with Select to high voltage. No firmware or driver configuration is required, you'll get 24-bit output instantly.

This I2S MEMS microphone is bottom ported, so make sure you have the hole in the bottom facing out towards the sounds you want to read. It's a 1.6-3.6V max device only, so it is not for use with 5V logic (it's really unlikely you'd have a 5V-logic device with I2S anyway). Many beginner microcontroller boards don't have I2S, so ensure it's a supported interface before you try to wire it up! This microphone is best used with Cortex M-series chips like the SAMD21 or SAMD51, ESP32, RP2040 or RP2350, or single-board computers like the Raspberry Pi.

[For code, libraries, wiring examples, CAD files, Fritzing, and more, check out the guide!](https://learn.adafruit.com/adafruit-i2s-mems-microphone-breakout/)

### License

Adafruit invests time and resources providing this open source design, please support Adafruit and open-source hardware by purchasing products from [Adafruit](https://www.adafruit.com)!

Designed by Limor Fried/Ladyada for Adafruit Industries.

Creative Commons Attribution/Share-Alike, all text above must be included in any redistribution. 
See license.txt for additional details.

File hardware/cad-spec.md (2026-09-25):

# Explaining the A1-4RD base to an AI: the CAD side

## First, be clear about what you are asking for

An AI cannot hand you a good STEP file. It has no geometric kernel, no view of
your model, and no way to check a fit. What it *is* good at is everything
upstream and downstream of the geometry:

| Ask it for this | Not this |
|---|---|
| A written design spec you then model from | "Generate the enclosure" |
| Kinematics: linkage lengths, servo throw → jaw angle | An assembly file |
| Print orientation, overhang, tolerance, and shrink advice | A sliced G-code file |
| A parametric script (build123d / CadQuery / OpenSCAD) | A parametric Fusion file |
| A review of a design you describe back to it | A review of a screenshot it half-reads |

You are fluent in CAD. The leverage is in the **spec** and the **mechanism math**,
not in it drawing boxes. So the deliverable you should ask for is a dimensioned
specification and a decisions log — something you can model from in an hour —
plus a parametric script only if you want a throwaway first body to check
proportions.

## The spec skeleton — fill this in, then hand it over

The reason CAD requests to an AI come back useless is almost always that one of
these seven is missing. Fill each one, in this order.

**1. Origin and datums.** Where is (0,0,0), which way is +Z, what face sits on
the desk. Every dimension afterwards references this. Say it explicitly or you
will get answers in three different coordinate frames.

**2. Envelope.** Outer footprint, total height, and the internal volume left
after wall thickness. State the wall thickness you intend and the material.

**3. Interfaces — the actual content.** For each, position, orientation, and
tolerance:
- PCB: outline, mounting hole coordinates and diameter, standoff height, which
  edge the USB-C connector exits and how much clearance it needs to the wall.
- Servos: pocket dimensions for the body, screw hole spacing, output shaft
  position and axis, and how much sweep the horn needs unobstructed.
- Speaker: diameter, depth, sealed or ported chamber, grille pattern and open
  area, standoff from the wall.
- Microphone: the port hole diameter and the gap between the PCB mic and the
  outer surface. This one has a right answer acoustically and a wrong one.
- Button: cap diameter, travel, panel thickness at that spot, how it retains.
- Cable routing from base to head, and strain relief at both ends.
- SD card and USB access without disassembly, or an explicit decision that you
  accept disassembly.

**4. Assembly strategy.** How it comes apart, how many pieces, what fastens to
what — heat-set inserts, self-tapping screws, snap fit, magnets. Say which, and
the hole diameters that go with it. Also say what has to be serviceable versus
what can be permanent.

**5. Print constraints.** Printer, nozzle, layer height, material, and the
orientation you intend for each part. Then the rules that follow: max unsupported
overhang angle, minimum feature size, whether supports are allowed, and which
surfaces are cosmetic. State your clearance convention explicitly — e.g. 0.2 mm
for sliding fits, 0.1 mm for press fits, holes drawn 0.2 mm oversize — because
otherwise you will get generic advice you already know.

**6. Aesthetic intent.** This is the part people leave out and it is the whole
project. Say it in plain language: he is a classic English butler at six inches — dry,
warm, formal. The base should read as a butler's stand, not a gadget. "A1-4RD"
is a visual pun that goes on the base as a nameplate. Screws should not be
visible from the front. Give the AI the reference and the feeling; it will push
back on details that fight it.

**7. What is already fixed.** The jaw is driven from a precomputed angle curve,
so it moves continuously through speech rather than snapping open and shut —
which means the linkage needs smooth travel over a modest range, not a binary
open/closed action. The head nods. The figure is six inches. Those are settled.

## The kinematics ask — do this one separately

The jaw is the only real mechanism, and it is worth a dedicated conversation.
Give the AI: the jaw pivot location, the desired open and closed jaw angles, the
servo's usable rotation, the servo mounting position, and the space available for
a linkage. Ask it for link lengths and attachment points that map servo angle to
jaw angle smoothly, plus the resulting non-linearity across the range so you can
compensate in software if it matters. That is a solvable geometry problem and it
will do it well. Ask it to "design the jaw" and it will write you a paragraph.

## Copy-paste prompt

---

I am designing the 3D-printed base for a six-inch desk companion figure called
A1-4RD ("Alfred") — a butler character, dry and formal, not
a consumer gadget. The base houses a Raspberry Pi Zero 2 W on a custom carrier
PCB, a speaker, a microphone, a button, and the wiring up to two servos in the
figure (jaw and neck nod). I am fluent in CAD and printing, so I do not need
modeling instruction — I need a rigorous specification and the mechanism math.

I will give you the parameters below. Your job:

1. Ask me for anything missing before you produce anything. Do not fill gaps with
   assumptions.
2. Produce a **dimensioned specification** I can model from directly: every
   feature located against a stated origin, with tolerances and the reasoning
   behind each number. Not prose descriptions of features — coordinates and
   dimensions.
3. Produce a **decisions log**: each choice, the alternative you rejected, and
   why. I want to be able to argue with your reasoning.
4. Flag every place where my constraints conflict with each other, and every
   place a decision depends on something I have not measured yet.
5. Where a number is acoustically or mechanically load-bearing — the mic port,
   the speaker chamber, the servo pocket fit — say so and give me the rule, not
   just the value.

Be blunt about problems. If something I have specified will not print, will not
fit, or will sound bad, say so plainly and give me the fix.

My parameters:

[paste the seven-section spec here]

---

## Sequencing note

Do the PCB architecture stage first. Its stage-4 mechanical interface sheet —
board outline, hole coordinates, connector positions, component keep-out heights
— is exactly the input section 3 of this spec needs. Designing the enclosure
around a board that has not settled means doing it twice.

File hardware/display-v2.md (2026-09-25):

# V2 base display: preliminary interface

Goal: add an approximately four-inch screen to the base that shows Alfred's
spoken reply as readable text. Placement, touch support, and exact module are
still open. The initial working assumption is a screen on the front face that
shows captions without touch controls.

## Connection and data path

- Keep the Pi Zero 2 W for now. It exposes mini HDMI, not a DSI display port.
  A four-inch HDMI LCD can use the Pi's video output while the GPIO header stays
  available for I2S audio, servos, button, and indicator.
- Supply the LCD from a protected 5 V branch and include its backlight draw in
  the measured power budget. Do not power it through a thin Pi jumper wire in
  the final assembly. Route a short mini-HDMI cable with connector clearance,
  bend radius, and strain relief inside the base.
- `brain/voice_server.py` already sends `{"text": ..., "audio": ...}` for each
  voiced sentence. `client/talk.py` reads these frames and queues the audio.
  The Pi client can hand each `text` value to a local caption view as the audio
  is queued. This gives sentence-level captions. Word-by-word highlighting
  would need timing data that the current server does not send.
- The caption view should clear when a new turn begins, wrap and scroll long
  replies, show the most recent sentence in large type, and turn the backlight
  down when idle. Treat any text from private memory as visible to everyone
  who can see the base.

## Mechanical implications

- Four inches is a diagonal, not a panel footprint. Select a real module and
  use its panel, PCB, mounting-hole, connector, and cable drawings before
  fixing the base diameter or front angle. A landscape display will likely
  make the base wider than the six-inch figure.
- Keep the display/bezel replaceable. A removable front panel lets a first
  body be built without a screen while preserving a V2 upgrade path.
- Keep the speaker outlet and mic port away from the LCD cavity. The screen
  panel should not become the speaker baffle or block the acoustic path.

## Prototype test

Before committing to a screen or larger base, connect a small HDMI monitor to
the Pi and render captions from the existing sentence frames. Check text size
at desk viewing distance, first-caption timing, scrolling during long replies,
and simultaneous audio playback. Then bench-test the chosen four-inch module
for its actual current and connector clearance.

One example to evaluate is the [Waveshare 4inch HDMI LCD](https://www.waveshare.com/wiki/4inch_HDMI_LCD),
an 800×480-class IPS module (native panel orientation is 480×800) that requires
an HDMI cable on the Zero 2 W. Its resistive touch function uses additional
GPIO/SPI resources, so leave touch disconnected if the screen only displays
captions. This is a candidate, not a selected part.

Sources: [Pi Zero 2 W interfaces](https://www.raspberrypi.com/products/raspberry-pi-zero-2-w/),
[Waveshare module guide](https://www.waveshare.com/wiki/4inch_HDMI_LCD).

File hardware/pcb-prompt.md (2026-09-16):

# Prompt: A1-4RD base PCB

Paste everything below the line into the other AI. Fill the four `<<< >>>` blanks
first — everything else is already decided.

---

You are an electronics design engineer helping me design a small custom PCB. I
have designed PCBs before at a hobby level but this is the most integrated board
I have attempted, so I want you to be actively skeptical of my choices and tell
me where I am about to make a beginner mistake. Do not be agreeable.

## What the board is for

I am building a six-inch 3D-printed desk companion called A1-4RD ("Alfred") — a
character, not a smart speaker. It has a moving jaw and a nodding head, listens
for a wake word, and talks. All heavy compute (speech-to-text, LLM, text-to-
speech) happens on a separate headless Linux server on my LAN. The board in the
figure's **base** is a thin client only: it captures audio, plays audio, drives
two servos, reads one button, and talks to the server over Wi-Fi.

This board replaces a laptop that currently does that job over an SSH tunnel, so
the software side is already working and is not in scope. I need the hardware.

## Fixed decisions — do not relitigate these

- **Compute is a Raspberry Pi Zero 2 W**, used as a module. My board is the
  carrier; the Pi plugs into it via the 2x20 0.1" header. I want the Pi
  removable (SD card access, and I do not want to solder a $15 board down).
- **Audio is I2S in and out**, not USB, not analog. Digital MEMS mic in, Class-D
  I2S amp out to a small speaker.
- **Two hobby servos**: one jaw, one neck nod. Standard 3-wire, 5V, ~9g class
  (SG90/MG90S). They are driven by GPIO PWM from the Pi unless you convince me
  otherwise.
- **One momentary button** on the base. This is a security control, not a
  convenience: the assistant keeps per-person memory, and pressing the button is
  how a user asserts identity so it will not read one person's private notes to
  another. Treat it as a deliberate physical input, debounced properly.
- **Single USB-C input, 5V.** One cable to the base, nothing else.
- The board lives entirely inside a 3D-printed enclosure I am designing in
  parallel. Mechanical constraints below are real, not aspirational.

## Blanks I need to fill

- Enclosure internal envelope available to the PCB: <<< e.g. 80 mm x 80 mm
  footprint, 22 mm internal height >>>
- Speaker I intend to use: <<< e.g. 4Ω 3W, 28 mm round, or "recommend one" >>>
- Assembly: <<< hand-solder everything / JLCPCB economic assembly for the
  fine-pitch parts and hand-solder the rest / full turnkey assembly >>>
- Quantity and rough budget ceiling per board: <<< e.g. 5 boards, $40 each >>>

## Functional requirements

1. Accept 5V from USB-C, protected, and distribute it to three loads: the Pi,
   the audio amplifier, and the servos.
2. Power the servos from a rail that cannot brown out the Pi. Servo stall current
   is the dominant transient in this design and I expect it to be the thing that
   crashes the Pi if I get it wrong.
3. I2S digital microphone, positioned so I can port it acoustically to a hole in
   the printed shell.
4. I2S Class-D amplifier driving one small speaker, with a sensible output
   filter for the speaker I pick.
5. Two 3-pin servo headers, keyed or clearly silkscreened, with the signal lines
   protected against a shorted or miswired servo.
6. One momentary button, hardware-debounced or explicitly documented as software-
   debounced with the RC values chosen.
7. A status indicator visible through the enclosure — single LED or one
   addressable LED, your call, argue for one.
8. Test points on every power rail and on the I2S clock lines.

## Constraints and things I already know are traps

Address each of these explicitly in your answer. If one does not apply, say so
and why.

- **USB-C CC pull-downs.** I know a USB-C receptacle without 5.1k resistors on
  CC1 and CC2 gets no power from a compliant charger. Confirm the exact
  configuration for a sink-only, 5V-only device.
- **Shared I2S bus for simultaneous capture and playback.** The Pi has one I2S
  peripheral. I want mic and amp on it at the same time, sharing BCLK and LRCLK
  with separate data lines. Tell me honestly whether this works reliably on a Pi
  Zero 2 W with mainline Linux drivers, which specific mic and amp parts are
  known-good for it, and what the failure mode is if it does not. If it does not
  work, propose the alternative and what it costs me in board area and money.
- **Servo transients.** Specify the bulk capacitance, the rail topology, and
  whether the servo rail needs its own regulator or can share the input. Show me
  the worst-case current budget as a table: Pi Zero 2 W peak, amp at full output,
  two servos stalled simultaneously, sum, and the input supply I therefore need.
- **Ground.** This board has a switching amplifier, a sensitive digital mic, and
  two motors on it. Tell me the grounding and placement strategy, not just
  "use a ground plane."
- **Trace widths.** Give me actual numbers for the servo rail and the main 5V
  rail on 1 oz copper, with the assumed temperature rise.
- **Pi header pin conflicts.** Produce a complete pin assignment table for the
  2x20 header showing every pin I use, what it does, and confirming I have not
  collided with the I2S peripheral pins or an I2C EEPROM address.
- **Mechanical.** Board outline, mounting hole positions and diameter, connector
  edge positions, and maximum component height per zone must be things I can hand
  straight to my CAD model. Assume M3 hardware unless you argue for M2.5.
- **Part availability.** Every part in the BOM must have an LCSC part number and
  be in stock. No unobtainium, no parts that only exist on a breakout board.

## What I want you to produce

Work in this order and stop for my input between stages 1 and 2.

**Stage 1 — architecture.** A block diagram in text, the power budget table, the
answer to the shared-I2S question, and the Pi pin assignment table. List every
open question you need me to answer before schematic. Flag anything where you
are guessing.

**Stage 2 — schematic.** Full schematic as a netlist I can import into KiCad 9,
plus a human-readable per-block description with every part value justified. Not
a picture, not pseudocode — something I can actually import or transcribe without
inventing values.

**Stage 3 — BOM and layout guidance.** BOM with LCSC part numbers, footprints,
and quantities. Then placement zones, routing priorities, layer stackup, and a
pre-fab review checklist specific to this board.

**Stage 4 — mechanical interface sheet.** Board outline dimensions, hole
positions as coordinates from a stated origin, connector positions and their
required clearance to the enclosure wall, component keep-out heights, and where
the mic port and speaker must sit. This goes into my CAD model, so it needs to be
dimensioned, not described.

## How to work with me

- Ask before assuming. If a requirement is ambiguous, ask rather than pick.
- Show your reasoning on anything numerical. I will check it.
- If I propose something wrong, say it is wrong and why, then give the fix.
- Prefer boring, well-documented parts over clever ones.
- Tell me explicitly when you are uncertain about a claim, especially driver
  behavior and part availability, so I know what to verify before I spend money.

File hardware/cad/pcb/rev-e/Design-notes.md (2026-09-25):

# Alfred revision E design notes

Pi Zero 2 W carrier; ICS-43434 I2S microphone; MAX98357A amplifier and enclosed 4-ohm/3-W speaker; one FS90 positional jaw servo. Four layers, 120 x 94 mm, nominal 1.6 mm FR-4, 35 um finished copper on every layer. Fixed mechanical interfaces retain revision B geometry. CAD-checked, unbuilt first article.

## Input power

Use the Raspberry Pi 27 W supply with its 5.1 V/5 A PD profile. CYPD3177 requests the selected 5 V/5 A contract. Its fallback switch output is unconnected, so an inadequate charger may leave the board off. A charger's headline wattage does not prove this profile. Never simultaneously power the Pi from its own connector and the carrier header.

Q1/Q2 are now **Vishay SI4459BDY-T1-GE3**, common-source back-to-back P-channel switches in the existing SO-8 footprint. Maximum on-resistance is 8.2 milliohms at -4.5 V and 25 C. At 4.1 A the pair contributes 0.06724 V drop and 0.276 W total dissipation at that specified point. Hot resistance and PCB/connector losses add to this. Verify gate voltage, startup timing and package temperatures.

R2 changes to 100k. Against the controller's maximum 3k pull-down plus R1=1k, the ideal resistor ratio gives 96.15% of source voltage as gate-source drive, before leakage. This shares an existing BOM value. D1 retains the 10 V gate clamp. Changed gate charge means PD-controlled startup/inrush must still be measured.

Revision E is scoped to the bare Pi Zero 2 W, onboard audio and one FS90. The design target is <=1.65 A on PI_5V (0.75 A Pi allocation, 0.85 A amplifier allocation, 0.05 A other) and <=0.80 A on the powered servo branch, 2.45 A combined. These are acceptance limits, not measured consumption. External USB loads, other Pi models and a sustained servo stall are outside this envelope. The previous 4.1 A allocation is withdrawn: it was not a validated operating capability.

## Protected rails and corrected enable input

U2/U3 remain TPS259470LRPWR with reverse-current blocking and latch-off fault behavior. Their central footprint lands are IN/OUT, not ground. R101=1.65k 0.1% gives about 2.02 A nominal Pi/audio current limit; R102=3.32k gives about 1.004 A nominal servo limit. Validate tolerances, startup and fault recovery with electronic loads.

The 34k/10k OVP dividers retain 5.28 V nominal cutoff, approximately 5.20-5.39 V including the specified threshold and resistor limits. OVP is a cutoff, not a 5 V regulator. Keep the amplifier within its operating voltage range.

**New EN protection:** R114=10k connects PD_5V to PI_EN_UVLO; R115=10k connects that node to ground. D101=MMSZ5V1T1G has cathode on PI_EN_UVLO, anode on ground. Normal EN voltage is about 2.55 V at 5.1 V input, comfortably above its approximately 1.2 V threshold.

Under a positive input fault, R114 limits current and D101 limits EN voltage. With an illustrative 28 V applied to this network alone, R114 current is below 2.8 mA and power below 80 mW; subtract the R115 current to obtain zener current. The diode's specified maximum is 5.36 V at 5 mA and 25 C, below EN's 6.5 V absolute maximum. Verify transient overshoot and temperature. This calculation does **not** authorize applying 28 V to the complete carrier or Pi; the other parts and USB protection impose separate limits.

C101 is now 10 nF C0G, 5%; C102 remains 4.7 nF. The Pi/audio ramp is about 0.20 V/ms (25.5 ms to 5.1 V); its 2200 uF reservoir draws about 0.44 A nominal during charging. The servo ramp remains about 0.426 V/ms (12 ms) and 0.43 A nominal reservoir charging current. Keep the amplifier and servo disabled during Pi startup. A screening estimate using +20% bulk capacitance, -5% timing capacitance and the 3.82/2.21 maximum/typical dVdt charging-current ratio gives about 0.96 A Pi reservoir inrush; adding the 0.75 A Pi allocation gives 1.71 A. This is below the 1.8 A minimum listed overcurrent threshold at 1.65k, but is not a guaranteed slew-rate bound: measure real startup, internal transfer variation and Pi boot current. The divider's 0.1% resistance tolerance makes the approximate current-threshold range 1.798-2.202 A. Overcurrent limiting is not instantaneous and may terminate in thermal latch-off.

## Precision supervisor and hardware arm latch

U4 is TPS389001DSET in a six-pad 1.5 x 1.5 mm WSON footprint. R107=32.0k 0.1% and R108=10k 0.1% monitor the protected Pi rail. RESET_N is SUPPLY_OK. R109 is now a 2.2k pullup to PI_3V3, not a feedback resistor. C109 bypasses U4. C111 is now a 100n delay capacitor; MR is tied high.

Nominal falling threshold: 1.15*(1+32.0/10) = **4.8300 V**. Nominal rising threshold: 1.157*(1+32.0/10) = **4.8594 V**. Including +/-1% supervisor thresholds, resistor tolerances and a conservative +/-100 nA sense-current term gives **4.771-4.889 V falling** and **4.800-4.919 V rising**. These are static bounds at the sensing point. Delay, trace/contact drop to the Pi and reservoir ESR still matter; this does not guarantee 4.75 V at the Pi header during all transients.

C111 gives about **107 ms nominal** reset-release qualification. It holds SUPPLY_OK low until the rail remains healthy; it does not delay initial detection by 107 ms. TPS3890 specifies an 18 us typical detection delay at 3.3 V with 5% overdrive, not a guaranteed maximum for small overdrive. Timing and capacitor tolerances change the recovery interval.

U11 is **Nexperia 74AUP1G74DC,125**, powered from PI_3V3 and bypassed by C112. D (pin 2) and active-low set (pin 7) are high. Active-low reset (pin 6) is SUPPLY_OK. Clock (pin 1) receives SERVO_REQUEST. Q (pin 5) is SERVO_ARMED; complement Q (pin 3) is unconnected. U5 ANDs SERVO_ARMED with SERVO_REQUEST to drive the servo eFuse.

A detected supply fault asynchronously clears the latch. Recovery with request held high leaves the servo OFF. A fresh low-to-high request after supply-good qualification is required to re-arm. Request low always disables power through U5. Software must not automatically pulse request repeatedly after a fault. The supervisor power-on reset initializes the latch; verify actual Pi_3V3 startup/shutdown ramps.

Use the specified AUP part. Its Schmitt inputs permit 200 ns/V transitions; the initial LVC candidate permits only 10 ns/V. R109=2.2k limits reset-release RC rise time. At an illustrative total SUPPLY_OK load of 100 pF, 2.2RC/(0.8*3.3) is about 183 ns/V. Measure at U11 pin 6 and require <=200 ns/V; do not attach long external leads. Do not substitute the LVC candidate without edge conditioning.

R107 is the catalogued Yageo RT0805BRD0732KL; the earlier 32.1k MPN was not verified and is removed. Threshold values above include initial resistor tolerances. The 25 ppm/C resistor temperature coefficients also matter: the validation script separately evaluates opposing drift up to 100 C from the 25 C reference. This widens the bounds and reduces the lowest cutoff margin. Neither static bounds nor this supervisor can guarantee no transient below 4.75 V.

At the new acceptance loads and 5.1 V input, the same 25 C mixed maximum/typical model used for revision D gives PI_5V about 5.026 V before servo enable and 5.013 V while running. Against the initial-tolerance upper thresholds, the margins are about 108 mV and 124 mV. Much of this improvement comes from the smaller supported load, not from the resistor change. R101 now enforces a lower overload threshold; it does not regulate normal load current or guarantee a hard 2.02 A ceiling during transients.

Use `Power-acceptance.md` and `software/validate-hardware-logic.py` for the stronger sensitivity calculation: 45 milliohm eFuse maximum, a stated 1.5x engineering allowance on MOSFET resistance, resistor temperature drift and 20 mV additional PCB/header loss. The MOSFET hot factor and the PCB loss allowance must be measured; they are not manufacturer guarantees. Minimum voltage is specified at the input connector pads, so upstream cable/contact loss must be accounted for separately. This turns the earlier vague power claim into a constrained build target; it does not prove the specified supply meets it.

Bench acceptance remains required. If input voltage or measured path loss fails the envelope, the power-path problem is not closed: qualify a lower supported load or redesign the power conversion/path. Do not bypass protection or lower R107 further to hide a failed load test.

## Audio

**Do not fit R304.** Floating GAIN_SLOT selects 9 dB. The datasheet full-scale reference plus gain is 2.1+9=11.1 dBV, or 3.589 Vrms, mathematically 3.221 W into 4 ohms before rail limitation/filter loss. This removes the previous approximately 0.81 W gain limit, but does not promise clean 3 W speech output. Use software attenuation and start quietly. The optional 100k R304 can be fitted for a quieter 3 dB variant.

All other amplifier decoupling/filter parts remain fitted. Neither speaker lead is ground. Do not connect an earth-referenced oscilloscope ground to either speaker terminal. L1/L2 remain 10 uH each, C306=220 nF differential, C307/C308=1 nF to ground; ideal differential resonance is about 75.9 kHz. Validate response/EMI with real wiring.

Pi drives BCLK/LRCLK; microphone and amplifier use separate data wires. Use standard I2S, 48 kHz, two 32-bit slots and 3.072 MHz BCLK. Capture and playback use the left slot. R301=47 ohms filters microphone supply with local capacitors. Keep the bottom acoustic bore free of solder, flux and cleaning liquid.

The `software/` directory supplies an overlay using the Raspberry Pi voiceHAT interface drivers, changed to Alfred's GPIO17 amplifier enable. Source review supports the intended duplex format/clock arrangement. Target compilation, boot and actual streaming remain untested. Echo cancellation requires a separate playback-reference acoustic/software solution.

## Jaw, button and LED

GPIO12 hardware PWM feeds the SN74LVC1G07 buffer; R402 pulls up from the switched servo rail and R403 limits signal fault current. GPIO22 requests power, GPIO25 reads supply-good, GPIO27 reads active-low servo fault. Keep the request low by default. Do not use PCM-based servo timing while audio uses I2S. The unkeyed servo header is GND/+5 V/signal. Calibrate jaw endpoints with the linkage detached first.

The existing TL431/Q3/10-ohm dump circuit remains. Its ideal threshold is about 5.589 V; reference current, tolerance and dynamics change this. At 5.6 V the dump resistor draws about 0.56 A and dissipates 3.14 W when fully on. Validate regeneration pulses, loop stability, overshoot and enclosed temperatures. Keep the raised 5 W resistor clear of plastic/wiring as specified in assembly instructions.

The button retains RC filtering and a Schmitt buffer. Require at least 30 ms stable-state software debounce on both edges. GPIO24 drives the green LED through 680 ohms.

## Release and sources

Follow `Fabrication-and-assembly.md`: measure PD negotiation, startup, EN voltage, current limiting, OVP, supply-good trip points, Pi-header droop, regeneration and component temperature, then test 30 minutes of simultaneous audio under Wi-Fi/jaw load. Preserve the antenna keepout. CAD results do not prove these behaviors. Purchasing estimates are in `Cost-and-purchasing.md`.

- [Si4459BDY](https://www.vishay.com/docs/76759/si4459bdy.pdf)
- [MMSZ5V1T1G series](https://www.onsemi.com/pdf/datasheet/mmsz2v4t1-d.pdf)
- [TPS25947](https://www.ti.com/lit/ds/symlink/tps25947.pdf)
- [TPS3890](https://www.ti.com/lit/ds/symlink/tps3890.pdf)
- [Nexperia 74AUP1G74](https://assets.nexperia.com/documents/data-sheet/74AUP1G74.pdf)
- [CYPD3177](https://www.infineon.com/assets/row/public/documents/24/49/infineon-cypd3177-24lqxq-datasheet-en.pdf)
- [MAX98357A](https://www.analog.com/media/en/technical-documentation/data-sheets/MAX98357A-MAX98357B.pdf)
- [Audio integration sources and target setup](software/README.md)

Changed passive specifications: [R107 catalog entry](https://www.digikey.com/en/products/detail/yageo/RT0805BRD0732KL/17024521), [R101 catalog entry](https://www.digikey.com/en/products/detail/yageo/RT0805BRD071K65L/1075688), [C101 manufacturer specification](https://yageogroup.com/download/specsheet/C0805C103J5GACTU). These links establish component identity; purchasing is deferred.

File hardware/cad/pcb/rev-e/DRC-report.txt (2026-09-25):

Revision D: 0 DRC violations; 0 unconnected items; 0 schematic parity issues.
Full results and ignored categories: DRC-report.json

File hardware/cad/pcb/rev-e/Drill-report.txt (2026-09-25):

Drill report for Alfred.kicad_pcb
Created on 2026-09-12T17:35:02

Copper Layer Stackup:
    =============================================================
    L1 :  F.Cu                      front
    L2 :  In1.Cu                    in1
    L3 :  In2.Cu                    in2
    L4 :  B.Cu                      back

Drill file 'Alfred-PTH.drl' contains
    plated through holes:
    =============================================================
    T1  0.300mm  0.0118"  (169 holes))
    T2  0.600mm  0.0236"  (4 holes)  (with 4 slots)
    T3  0.800mm  0.0315"  (4 holes))
    T4  0.900mm  0.0354"  (2 holes))
    T5  1.000mm  0.0394"  (45 holes))
    T6  1.100mm  0.0433"  (6 holes))
    T7  1.200mm  0.0472"  (2 holes))

    Total plated holes count 232

Drill file 'Alfred-NPTH.drl' contains
    unplated through holes:
    =============================================================
    T1  0.500mm  0.0197"  (1 hole)
    T2  0.650mm  0.0256"  (2 holes))
    T3  2.700mm  0.1063"  (4 holes))
    T4  3.200mm  0.1260"  (4 holes))

    Total unplated holes count 11

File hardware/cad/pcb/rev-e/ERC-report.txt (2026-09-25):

ERC report (2026-09-12T17:34:24, Encoding UTF8)
Report includes: Errors, Warnings

***** Sheet /

***** Sheet /USB-C: fixed 5 V / 5 A contract/

***** Sheet /Protected rails and servo undervoltage override/

***** Sheet /Raspberry Pi physical header and shared I2S/

***** Sheet /Digital microphone and bridge speaker amplifier/

***** Sheet /Jaw interface, energy dump, button and status/

 ** ERC messages: 0  Errors 0  Warnings 0

 ** Ignored checks:
    - Global label only appears once in the schematic
    - Four connection points are joined together
    - SPICE model issue
    - Assigned footprint doesn't match footprint filters

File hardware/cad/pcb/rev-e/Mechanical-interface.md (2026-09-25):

# Alfred mechanical interface — millimetres, revision E

This defines a proposed carrier/enclosure interface within the confirmed **127 × 101.6 × 50.8 mm internal housing volume**. These are design coordinates, not measurements of an existing printed shell. Use the supplied DXF for board outline/holes and CSVs for coordinates. Purchase-part fit and the header mating height require a physical fit check before freezing the enclosure.

## Coordinate system and outline

Plan view looks down onto carrier components. **PCB origin is its front-left corner; X goes right, Y goes toward the back.** Z in this document is measured upward from the internal housing floor. The front/back edges are the long edges.

| Item | Dimensions / location |
|---|---|
| Internal housing | X 0–127, Y 0–101.6, Z 0–50.8 |
| Carrier outline, PCB coordinates | (0,0), (120,0), (120,94), (0,94); square corners |
| Carrier location in housing | Housing X = PCB X + 3.5; housing Y = PCB Y + 3.8 |
| Carrier underside / top | Z = 6.0 / 7.6; nominal 1.6 mm board |
| Carrier envelope tolerance | Outline ±0.2 mm, drill positions ±0.1 mm requested; confirm fab capability |
| Bottom parts | None; reserve underside Z 3.0–6.0 for trimmed through-hole leads |
| Carrier standoffs | Four M3 supports, floor to PCB underside = 6.0 mm; boss outside diameter ≤7.0 mm |

## Mounting holes

All holes are non-plated. Keep copper and components outside a 7.0 mm diameter at M3 holes and 6.0 mm diameter at Pi mounting holes; maintain electrical clearance to metal hardware. Use insulating washers where necessary.

| Ref | PCB X | PCB Y | Drill | Hardware |
|---|---:|---:|---:|---|
| H1 | 4.0 | 4.0 | 3.2 | M3 carrier |
| H2 | 116.0 | 4.0 | 3.2 | M3 carrier |
| H3 | 4.0 | 90.0 | 3.2 | M3 carrier |
| H4 | 116.0 | 90.0 | 3.2 | M3 carrier |
| H5 | 83.5 | 90.5 | 2.7 | M2.5 Pi support |
| H6 | 106.5 | 90.5 | 2.7 | M2.5 Pi support |
| H7 | 83.5 | 32.5 | 2.7 | M2.5 Pi support |
| H8 | 106.5 | 32.5 | 2.7 | M2.5 Pi support |

The Pi has factory holes on a 58 × 23 mm rectangle, 3.5 mm from its 65 × 30 mm outline edges. **Use M2.5 on the Pi; do not enlarge its holes for M3.** Use nylon Pi screws and supports, particularly at H8 inside the antenna exclusion region; do not put a brass spacer there. See the [official Pi drawing](https://datasheets.raspberrypi.com/rpizero2/raspberry-pi-zero-2-w-mechanical-drawing.pdf).

## Pi orientation and connector stack

The Pi body occupies PCB X **80–110**, Y **29–94**, with its SD end toward Y=94. The carrier socket is on the carrier top; a straight male header is soldered to the Pi underside. The Pi component side faces upward. Socket physical pin 1 is at **(84.77,85.63)** and pin 2 at **(82.23,85.63)**. For each succeeding pair, subtract 2.54 mm from Y; pin 39 is (84.77,37.37), pin 40 (82.23,37.37). Confirm pin-1 orientation on a 1:1 print before mating.

Use Samtec SSW-120-01-G-D socket with TSW-120-07-G-D male header. Nominal body-height sum 8.51 + 2.54 = **11.05 mm** between carrier top and Pi underside when fully seated. Set supports to the **measured assembled gap**, nominal 11.05 mm; use 11 mm spacers plus thin shims if needed. Do not pull the Pi down against an incorrect spacer height. Pi underside is nominal Z=18.65. Reserve **Z 18.65–28.0** for Pi PCB, components and SD handling.

The official outline drawing does not dimension the SD socket aperture. Therefore the proposed enclosure uses a generous **service window**, not an unverified close-fitting SD slot: housing X **81.5–115.5**, Z **16.5–28.0** at the back wall. Provide at least **20 mm of unobstructed external withdrawal space** and a removable cover or finger notch. Keep the tunnel clear from the Pi's rear edge (housing Y=97.8) to the exterior. Mounting screws must remain accessible after removing the cover.

Reserve PCB X **96–114**, Y **25–44** for the Pi antenna: no carrier copper on any layer, no tall components, and no metal brackets, cable bundles or speaker magnet in that volume. This is a conservative proposed region around the antenna end; verify alignment against the actual Pi revision.

## Connectors and controls

Rotations below are KiCad rotations in the routed board. The physical PCB coordinate mapping above is authoritative. CAD point (X,Y) maps to KiCad editor point (50+X,144−Y) mm.

| Item | PCB footprint origin | Orientation / clearance |
|---|---|---|
| J1 USB-C | (30.0,90.8), 180° | Mouth toward back, approximately at Y=94; reserve PCB X 24–36, Y 84–94 |
| J2 Pi socket pin 1 | (84.77,85.63), 0° | Long axis toward front; pin 2 is 2.54 mm left |
| J3 speaker terminal pin 1 | (57.0,28.0), 0° | Wire entry toward front; pitch 2.54 mm; 8 mm clear above screws and 10 mm free wire space in front |
| J4 servo pin 1 | (15.0,53.0), 90° | Header runs along X; reserve X 10–25, Y 48–58, up to Z=30 for plug/wire bend |
| SW1 origin | (105.0,12.0), 0° | Button actuator center = (108.25,9.75); vertical plunger from enclosure, not a sideways load |
| D3 LED pin 1 | (99.5,8.0), 0° | LED optical axis approximately (100.77,8.0); printed light pipe centered there |
| U6 microphone package center | (10.0,8.71), 0° | PCB acoustic hole center = (10.0,8.0), diameter 0.50 mm NPTH |

For USB, use a deliberately generous rear service opening: housing X **23.5–43.5**, Z **3.5–15.5**, with a clear 20 × 12 mm tunnel extending from housing Y=94 to the outer wall. The receptacle is recessed 3.8 mm from the internal rear boundary. The opening must admit the **plug overmold**, not just its metal tongue. Keep 30 mm of external straight cable space before bending. Wall thickness is an enclosure input, so the tunnel extends through whatever wall thickness you choose; its clear section stays 20 × 12 mm throughout.

J3 is internal; there is no need for an enclosure connector opening. Secure the speaker cable so pulling the shell does not load the terminal block. J4 is also internal; provide a retention clip and a service loop rather than letting its plug carry mechanical loads.

The B3F-1000 is a four-leg, two-net switch. The standard footprint origin is not the actuator center; the coordinates above include that offset. Leave about 0.2 mm plunger rest clearance and incorporate a travel stop; verify purchased actuator height and travel before printing the final plunger. The LED body can be raised on its leads to meet a light pipe; lead forming must preserve the height zone.

## Speaker, microphone port and height zones

The selected speaker body is approximately 70 × 31 × 17 mm. Stand it upright with the 70 mm dimension across the front, its 31 mm dimension vertical, and its 17 mm depth toward the back. Proposed body envelope in PCB X/Y and housing Z is **X 25–95, Y −3.8–13.2, Z 12–43**. This puts its face at the internal front boundary. Use a padded printed cradle with a **71 × 32 × 18 mm cavity**, centered on the nominal body, and a removable retaining strap. Do not rely on the supplier's ambiguous mounting-hole spacing. Keep at least 1 mm in front of the diaphragm/grille and preserve its factory rear enclosure.

The microphone is separated to the left of the speaker. Seal a **3 mm diameter annular gasket seat** around its underside acoustic hole. Provide a printed acoustic passage from housing **(13.5,11.8,Z=6.0)** to a **2 mm diameter front opening at housing X=13.5, Z=5.0**. Use a channel at least 1.5 mm clear diameter, avoid sharp steps/dead cavities, and keep its path separate from the speaker cavity. The gasket seals to the PCB underside; it must not plug the 0.5 mm bore. Reserve PCB X 7–13, Y 5–11 for the port/gasket and no copper near the bore. This duct's acoustic effect must be measured; dimensions are a mechanical starting point, not a calibrated microphone response.

| Zone, PCB X/Y | Maximum height above carrier top | Purpose |
|---|---:|---|
| X 22–98, Y 0–18 | 3.0 mm | Clearance below speaker cradle; no electrolytics/inductors here |
| X 80–110, Y 29–94, excluding socket/supports | 6.0 mm | Components below Pi; preserve 11.05 mm mating gap and Pi underside clearances |
| X 96–114, Y 25–44 | 0 mm carrier components | Antenna region, all copper excluded |
| X 25–78, Y 55–86 | 28.0 mm | Tall power capacitors; C105 seated height can reach 27 mm |
| X 25–65, Y 38–54 | 15.0 mm | Raised dump resistor; keep plastic and wire insulation at least 5 mm away |
| X 10–25, Y 48–58 | 22.4 mm including cable | Servo plug/bend volume, absolute top Z=30 |
| X 10?23, Y 59?69 | 18.0 mm | C106 servo bulk capacitor; seated height up to 17 mm |
| Remaining carrier area | 12.0 mm | General circuitry; individually respect connector/control exceptions |

Maximum planned speaker top is Z=43, leaving 7.8 mm below the internal ceiling. Tall capacitor top is at most Z=35.6. The Pi service volume stops at Z=28. These allowances fit the 50.8 mm housing height without using it as a component-height entitlement everywhere.

The jaw servo belongs in the moving-head mechanism and is not assigned a base PCB mounting location. Its approximate 23.2 × 12.5 × 22 mm body and mounting tabs must be integrated against its purchased drawing. Final linkage geometry, cable exit toward the head and shell-wall thickness are the remaining enclosure-specific inputs; they do not change this carrier outline.

## Routed-board changes

All electrical parts are placed inside the outline. D3 moved 0.5 mm left to clear the button body; its optical axis is now PCB (100.77,8.0). The resistor and servo capacitor height zones above supersede revision A. `Placement-coordinates.csv` contains every footprint origin and rotation from the final PCB. The two-layer signal routing and four-layer copper stack are described in `Fabrication-and-assembly.md`.

The STEP file is the bare carrier, without component models. The dimension tables define enclosure placement; the 3D preview contains generic or missing component models and does not represent the installed Pi or speaker.

Revision E retains all fixed mechanical coordinates. The three small protection parts occupy existing low-height circuitry space; the connector stack and enclosure dimensions are unchanged.

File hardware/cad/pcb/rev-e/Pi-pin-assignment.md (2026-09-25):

# Pi header — physical pin numbers

View this as a pin-number table, not a carrier-bottom physical drawing. All unused GPIO pins are unconnected on the carrier.

| Physical pin | BCM GPIO | Carrier net | Function |
|---:|---:|---|---|
| 1 | — | PI_3V3 | 3.3 V supplied by Pi |
| 2 | — | PI_5V | 5 V into Pi |
| 3 | 2 | NC | I2C1 available; no carrier connection |
| 4 | — | PI_5V | 5 V into Pi |
| 5 | 3 | NC | I2C1 available; no carrier connection |
| 6 | — | GND | Ground |
| 7 | 4 | NC | Unused; no carrier connection |
| 8 | 14 | NC | Unused; no carrier connection |
| 9 | — | GND | Ground |
| 10 | 15 | NC | Unused; no carrier connection |
| 11 | 17 | AMP_ENABLE | Amplifier enable, high = left playback |
| 12 | 18 | BCLK_PI | PCM_CLK / shared BCLK output |
| 13 | 27 | SERVO_FAULT_N | Servo fault input, active low |
| 14 | — | GND | Ground |
| 15 | 22 | SERVO_REQUEST | Servo power request output |
| 16 | 23 | BUTTON_N | Button input, active low |
| 17 | — | NC | Unused; no carrier connection |
| 18 | 24 | LED_GPIO | Status LED output |
| 19 | 10 | NC | Unused; no carrier connection |
| 20 | — | GND | Ground |
| 21 | 9 | NC | Unused; no carrier connection |
| 22 | 25 | SUPPLY_OK | Supply-good input |
| 23 | 11 | NC | Unused; no carrier connection |
| 24 | 8 | NC | Unused; no carrier connection |
| 25 | — | GND | Ground |
| 26 | 7 | NC | Unused; no carrier connection |
| 27 | 0 | NC | Reserved HAT EEPROM ID bus; no carrier connection |
| 28 | 1 | NC | Reserved HAT EEPROM ID bus; no carrier connection |
| 29 | 5 | NC | Unused; no carrier connection |
| 30 | — | GND | Ground |
| 31 | 6 | NC | Unused; no carrier connection |
| 32 | 12 | JAW_PWM | PWM0 / hardware jaw PWM |
| 33 | 13 | NC | Unused; no carrier connection |
| 34 | — | GND | Ground |
| 35 | 19 | LRCLK_PI | PCM_FS / shared LRCLK output |
| 36 | 16 | NC | Unused; no carrier connection |
| 37 | 26 | NC | Unused; no carrier connection |
| 38 | 20 | MIC_DATA_PI | PCM_DIN / microphone data input |
| 39 | — | GND | Ground |
| 40 | 21 | AMP_DATA_PI | PCM_DOUT / amplifier data output |

No EEPROM or I2C-addressed device is attached to the Pi. Pins 27/28 are untouched. The standalone PD controller HPI bus is also unconnected. GPIO12 PWM0 does not consume GPIO18/19/20/21 PCM signals. Disable PWM analog audio and do not run PCM-based servo timing libraries concurrently with I2S.

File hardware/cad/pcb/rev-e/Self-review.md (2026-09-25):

# Revision E closure and open validation

The unverified32.1k R107 purchasing MPN is fixed with catalogue32.0k RT0805BRD0732KL. Schematic, PCB, BOM, calculations and drawings are synchronized. The incomplete external BOM now includes missing essentials.

Power mitigation changes R101 and C101: about2.02A Pi/audio overcurrent threshold and about25.5ms nominal startup. A constrained1.65A Pi/audio plus0.80A servo target replaces the unsupported4.1A allocation. Lower startup demand and a smaller operating load increase calculated margin without adding placements. This reduces capability; it is not an equivalent4.1A redesign.

The full power-margin issue is not physically closed. Power-acceptance.md defines measurable requirements and includes maximum eFuse resistance, initial/temperature resistor tolerances, an explicitly assumed MOSFET hot factor and PCB loss. Validate the real supply, thermal conditions, startup and transients before relying on the jaw or Pi. The remaining tests cannot be performed against CAD files. Source checks did not justify adding a replacement input MOSFET as an unvalidated drop-in.

Purchasing, supplier baskets and orders are deferred. No claim is made that every remaining MPN is stocked. Clean DRC/ERC and a logic truth table do not prove power, audio, RF or mechanical behavior.

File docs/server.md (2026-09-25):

# Running Alfred

## The client

From the project root on the laptop, in PowerShell. The client starts any server services that are not
running and opens the SSH tunnels itself ([reaching the server](SSH.md)).

```powershell
.venv-tts\Scripts\python.exe client\listen.py            # speak: say "Alfred, ..."
.venv-tts\Scripts\python.exe client\listen.py --open     # no wake word
.venv-tts\Scripts\python.exe client\talk.py              # type, and hear him answer
python client\chat.py                                    # type, text only (standard library)
```

Each spoken turn prints what was heard, how long transcription took, and the longest pause left inside the
sentence: the data for tuning when a turn is considered over. **Ctrl+C** quits. Everything said is
remembered, exactly as in normal use.

Terminal chat directly on the server, with no audio:

```bash
cd ~/a1-4rd && .venv-rvc/bin/python brain/alfred.py
```

## Services

| Service | What it runs | Started by |
|---|---|---|
| Ollama | `gemma4:26b-a4b-it-q8_0` on the MI50 | systemd (`ollama`) |
| voice server | `brain/voice_server.py` | systemd (`alfred-voice`) |
| Whisper | `brain/whisper_server.py` | systemd (`alfred-whisper`) |
| SearXNG | metasearch | systemd (`alfred-searx`) |
| media service | `brain/media_server.py`, YouTube search and audio | systemd (`alfred-media`) |

All of them listen on localhost only; the laptop reaches them through SSH port forwarding.
`client/listen.py` still starts any that are not running. Install the units with
`sudo bash ops/services/install.sh`.

## Installed system pieces ([`ops/`](../ops))

| Unit | What it does |
|---|---|
| `mi50-fan.service` | fan speed from the MI50's junction and memory temperature; full speed if the sensor is lost |
| `a1-4rd-nightly-reboot.timer` | 3 a.m.: reboots only if up ≥ 60 h and idle (no RAID check, downloads, updates, SSH activity or GPU load). Opt out: `sudo touch /etc/a1-4rd-no-auto-reboot` |
| `alfred-voice`, `alfred-whisper`, `alfred-searx` | Alfred's services, up at boot and restarted if they crash ([`ops/services`](../ops/services)) |
| `01-keys-only.conf`, `tailscaled` | SSH by key only; reachable from any network through Tailscale, no open router port ([`ops/remote-access`](../ops/remote-access)) |
| `alfred-ollama-warm.service` | loads Alfred's model at boot so the first reply is not a 20 s load |
| `ollama.service.d/override.conf` | see below |

## Ollama settings

Why each setting in [`ops/ollama/override.conf`](../ops/ollama/override.conf) is there:

| Setting | Reason |
|---|---|
| `GGML_VK_DISABLE_HOST_VISIBLE_VIDMEM=1`, `RADV_PERFTEST=nogttspill` | the MI50 exposes only 16 GB to the CPU; without these half the model silently lands in system RAM (4 tok/s instead of 40) |
| `OLLAMA_NUM_PARALLEL=2` | the tool decider and Alfred's persona each keep their own cached prompt |
| `LLAMA_ARG_SWA_FULL=1`, `LLAMA_ARG_CTX_CHECKPOINTS=0`, `LLAMA_ARG_CACHE_RAM=0` | stop llama.cpp copying ~100 MB of cache off the card every request (−0.47 s per turn) |
| `OLLAMA_MAX_LOADED_MODELS=2` | Alfred + the embedder; anything extra evicts instead of spilling into RAM |
| `OLLAMA_KEEP_ALIVE=-1` | the model never unloads |

VRAM is ~31 of 32.75 GB in use. Loading another model onto the MI50 alongside Alfred will slow him down.
The board boots in legacy (CSM) mode; do not disable CSM.

## Useful checks

```bash
ollama ps                                                    # model loaded, 100% GPU
cat /sys/bus/pci/devices/0000:03:00.0/mem_info_gtt_used      # should stay under ~1 GB
sensors amdgpu-pci-0300                                      # MI50 temperatures and power
journalctl -u mi50-fan -n 5                                  # fan curve decisions
systemctl list-timers a1-4rd-nightly-reboot.timer
```

## What is not in git

Large assets live at the project root on the server: the virtual environments (`.venv-rvc`,
`.venv-whisper`), `voice-audition-distilled/` (his current voice), `tts-models/`, `rvc-model/`, and the
training data under `voice-distill/` and `piper-training/`.

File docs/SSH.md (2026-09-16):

# SSH to the A1-4RD server

```
ssh a1-4rd
```

Uses the `a1-4rd` alias in `~/.ssh/config` (host `xxx.xxx.xxx.xxx`, user `<user>`, key `~/.ssh/a1-4rd`).
Key-based; no password is needed to log in. `sudo` still asks for one.

The address comes from the router's DHCP and is not reserved. If `ssh a1-4rd` stops connecting, find the
server by scanning the LAN for port 22, check that its ed25519 host key matches the known one, and update
`HostName` in `~/.ssh/config`. (Another device on the LAN also answers on port 22 — check the host key.)

The project lives in `~/a1-4rd/` with the same layout as this repo, plus the git-ignored assets (venvs,
voice models, training data) at the top level.

Copy files back and forth:

```
scp persona/examples.md a1-4rd:~/a1-4rd/persona/
scp a1-4rd:~/a1-4rd/brain/alfred.py brain/
```

## From another network (Tailscale)

The server only accepts keys, and is on Tailscale as `a1-4rd`
([`ops/remote-access/install.sh`](../ops/remote-access/install.sh)). No router port is open: only devices signed
in to the same Tailscale account can reach it.

On the laptop, install Tailscale (`winget install --id Tailscale.Tailscale -e`), sign in with the same account,
and point the alias at the Tailscale name, keeping the LAN address as a fallback:

```
Host a1-4rd
    HostName a1-4rd
    User <user>
    IdentityFile ~/.ssh/a1-4rd
    IdentitiesOnly yes

Host a1-4rd-lan
    HostName xxx.xxx.xxx.xxx
    User <user>
    IdentityFile ~/.ssh/a1-4rd
    IdentitiesOnly yes
```

`listen.py` and `talk.py` use the `a1-4rd` alias, so they then work from any Wi-Fi unchanged. The Tailscale
name also survives the DHCP address changing. In the Tailscale admin page, disable key expiry for `a1-4rd`, or it
drops off the network after 180 days.

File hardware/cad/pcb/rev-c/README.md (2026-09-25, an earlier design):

# Alfred carrier - revision C

**Improved, routed 120 x 94 mm four-layer PCB for Alfred: Raspberry Pi Zero 2 W, ICS-43434 microphone, MAX98357A speaker amplifier and one FS90 jaw servo.** Open `Alfred.kicad_pro` in KiCad 10. This revision supersedes revision B for new prototype builds.

CAD validation: zero DRC violations, zero unconnected items, zero schematic parity issues, and zero ERC errors/warnings. **This is an unbuilt first article, not bench-qualified hardware.**

## What changed

- Q1/Q2 are onsemi FDS6673BZ MOSFETs with specified on-resistance at -4.5 V gate drive. R2 changes to the existing 100k value to improve gate drive.
- R114/R115 and D101 add a divided and clamped enable input for the Pi eFuse.
- The servo supply-good circuit now senses the protected Pi rail after the Pi eFuse, with earlier nominal shedding thresholds.
- **R304 is DO NOT FIT.** Leaving GAIN_SLOT floating selects 9 dB gain instead of 3 dB, removing the earlier approximately 0.8 W output limitation. Start playback quietly and verify clipping/power before maximum volume.
- The BOM distinguishes fitted parts, optional gain components and lean single-board purchasing quantities.
- `software/` contains an Alfred GPIO17 audio overlay source, a build script, a low-volume capture/playback smoke test and Pi setup instructions. Target compilation and hardware testing remain necessary.

## Files

- Native KiCad project, six schematic sheets and pinned project libraries: editable design.
- `Fabrication/`: freshly generated Gerber X2 files and separate PTH/NPTH drill files. Specify 35 um finished copper on **all four layers**, nominal 1.6 mm board, ENIG and the documented stencil.
- `Schematic.pdf`, `Assembly-top.pdf`, `Copper-layers.pdf`: current drawing exports. Assembly drawing crosses out the unfitted R304.
- `BOM-grouped.csv`: fitted quantities and lean purchase quantities for **one** board. Assemblers may require additional attrition parts. `BOM-do-not-fit.csv` identifies omitted components.
- `BOM-external.csv`: servo, speaker, supply, Pi male header, PCB and hardware allowances. Pi itself and assembly labor are excluded.
- `Design-notes.md`, `Fabrication-and-assembly.md`, `Mechanical-interface.md`: design decisions, assembly instructions and preserved enclosure interface.
- `Validation.txt`, `DRC-report.json`, `ERC-report.txt`: final CAD results. `SHA256SUMS.txt` records package checksums.

## Cost

Planning allowance: **$43.06 fitted board components**, plus $55.35 inherited external/PCB/hardware allowances, approximately **$98.41 excluding Pi**, shipping, tax, assembly, stencil and enclosure printing. Most prices remain estimates. The previous recommended purchase basket included many unnecessary spares; the revised lean board-parts basket is approximately $17.74 lower on the documented mixed estimate/price basis. The fitted circuit itself is approximately $2.44 more expensive because of the improvements. See `Cost-and-purchasing.md`; this is not a supplier quote.

## Self-review update (2026-09-11)

See `Self-review.md`. Fresh CAD checks pass, but the servo supply-good thresholds have inadequate demonstrated margin at the stated maximum load. The jaw may fail to enable or cycle as the Pi rail recovers. A software retry policy alone cannot guarantee hardware latch-off during fast transients. This remains an engineering prototype requiring power-margin and startup validation before relying on jaw operation. Manufacturing job dimensions and an obsolete BOM threshold note were corrected.

## Before relying on Alfred

Use the specified Raspberry Pi 27 W USB-C supply (5.1 V / 5 A PD profile). First validate PD startup and rails with the Pi and servo disconnected. Then verify audio, finally supervised jaw movement. Measure the Pi header voltage during Wi-Fi, loud speech, servo acceleration and reversal, verify the regeneration clamp and temperatures, and validate 30 minutes of full-duplex operation. The original enclosure geometry and fixed connector positions remain unchanged; verify actual purchased-part fit and jaw limits.

The source revision B folder was not modified. No board order or purchase was placed.

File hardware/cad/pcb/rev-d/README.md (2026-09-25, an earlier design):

# Alfred carrier - revision D

PCB for Raspberry Pi Zero 2 W, ICS-43434 microphone, MAX98357A amplifier and one FS90 jaw servo. Four copper layers, 120 x 94 mm. Open `Alfred.kicad_pro` in KiCad 10.

Revision D replaces revision C for prototype builds. **The circuit changes are complete and CAD-checked; this remains unbuilt hardware requiring bench qualification.**

## Fixes

- Lower-loss SI4459BDY-T1-GE3 input MOSFETs reduce calculated pair drop at 4.1 A from 98 mV to 67 mV at the stated 25 C rating.
- TPS389001DSET replaces the old comparator. Nominal cutoff is 4.842 V; recovery threshold is 4.871 V followed by about 107 ms stable-rail qualification.
- A Nexperia 74AUP1G74 hardware arm latch prevents rail recovery from restarting the servo while request stays high. Re-arming requires a deliberate low-to-high request after supply-good.
- R304 remains unfitted for 9 dB amplifier gain; its stencil apertures are now removed.
- Connector and mounting-hole positions remain unchanged.

## Validation and limits

Fresh DRC, schematic parity and ERC pass. `Validation.txt` records netlist, manufacturing and logic checks. The latch passed 65,536 eight-event sequences in a truth-table model; this is not analog or physical testing.

The earlier nominal threshold conflict is removed. At the illustrative maximum load, calculated static margin to the upper threshold is about 42 mV when enabling and 51 mV while running, before additional cable/contact/PCB losses. Temperature and actual load still limit jaw availability. Measure the Pi-header voltage and verify intended operation under combined load. See `Design-notes.md` and `Self-review.md` for bounds and acceptance tests.

## Build files

`Fabrication/` contains current Gerbers, PTH/NPTH drills and normalized job dimensions. The three PDFs are current schematic, assembly and copper exports. Use `BOM-grouped.csv`, `BOM-do-not-fit.csv`, `Placement-coordinates.csv` and `Fabrication-and-assembly.md` together. The placement table includes THT and mechanical items; confirm machine rotation conventions with the assembler.

`software/` contains audio overlay source, a quiet duplex test and the revised jaw-enable sequence. Target compilation and physical audio testing remain necessary. Use the specified Raspberry Pi 27 W USB-C supply through this carrier; do not simultaneously power the Pi's own power connector.

## Cost

Fitted electronics allowance: **$43.71**, approximately **$0.65 more than revision C**. Combined inherited allowance: **$99.06 excluding Pi**, shipping, tax, assembly, stencil and enclosure. This is a mixed planning estimate, not a checkout quote; see `Cost-and-purchasing.md`.

Start with electrical loads and the jaw linkage detached. Validate startup, fault latching, Pi-header minimum voltage, audio and servo regeneration before relying on Alfred. Previous revisions remain in separate folders.

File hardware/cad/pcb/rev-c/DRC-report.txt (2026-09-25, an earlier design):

Revision C: 0 DRC violations; 0 unconnected items; 0 schematic parity issues.
See DRC-report.json for full settings and results.

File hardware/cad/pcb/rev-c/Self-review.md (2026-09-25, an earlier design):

# Alfred revision C self-review - 2026-09-11

**Verdict: CAD-consistent engineering prototype, with an unresolved servo power-margin issue. Do not interpret the earlier clean DRC/ERC result as proof that Alfred will operate reliably.** This review checked saved revision C files independently of the prior status report. No hardware was available.

## Findings

### P1 - Servo enable has insufficient demonstrated voltage margin (unresolved)

The nominal comparator thresholds are 4.960 V rising and 4.915 V falling, before intrinsic hysteresis and component tolerances. Using the stated 2.85 A Pi/audio allocation with the servo off, a 5.1 V input, the FET pair's specified 25 C 24 milliohm maximum, and the eFuse's typical 28.3 milliohm resistance gives:

`5.1 - 2.85 * (0.024 + 0.0283) = 4.951 V`

That is already below the ideal rising threshold, before cable, connector, PCB and return-path losses. At 4.1 A total input and 2.85 A on the Pi/audio branch:

`5.1 - 4.1 * 0.024 - 2.85 * 0.0283 = 4.921 V`

Only about 6 mV remains above the ideal falling threshold. These illustrative mixed maximum/typical calculations are not a complete worst-case proof or a prediction of every unit. They establish that the claimed load allocation does not have demonstrated servo-availability margin. Hot resistance and comparator tolerances must be included. A narrow trace feeding a sense input does not by itself imply that load current flows through it; a full copper/contact resistance model was not performed.

Consequence: under high Pi/audio load the jaw may not enable, or it may shed power and recover repeatedly. Resolve through measured rail/drop/threshold data and, if necessary, a revised power path and supervisor hysteresis. Simply lowering thresholds can sacrifice Pi brownout protection.

Sources: [FDS6673BZ gate-drive and resistance specifications](https://www.onsemi.com/download/data-sheet/pdf/fds6673bz-d.pdf), [TPS25947 on-resistance and current limiting](https://www.ti.com/lit/ds/symlink/tps25947.pdf), [TLV3012B comparator/reference specifications](https://www.ti.com/lit/ds/symlink/tlv3012.pdf).

### P1 - Software retry policy does not provide a hardware latch (unresolved)

U5 combines SUPPLY_OK with GPIO22. If GPIO22 stays high while the Pi rail dips and recovers, U5 can re-enable U3 before Linux notices the event. The eFuse's own latch-off fault response does not turn every external enable transition into a latched fault. The documentation's instruction to clear GPIO22 is useful but cannot guarantee no fast hardware retries. Scope startup and load-step behavior; dependable one-shot shutdown needs an explicit hardware latch or a validated equivalent. No hardware latch was added in this review.

### P2 - Manufacturing metadata and BOM note (fixed)

The Gerber job had 120.1 x 94.1 mm, while the documentation claimed centerline dimensions. Verified all four Edge.Cuts segments define exactly 120 x 94 mm. Corrected job Size to those centerline dimensions and documented that KiCad's regenerated job includes stroke width. Copper and outline geometry were not changed.

R109's purpose text still quoted revision B thresholds. Corrected it in design-data.json, BOM.csv and Component-ledger.md to match R107 and the revision C calculations.

The default DNP R304 still has paste apertures. This is not a netlist fault; assembly instructions now explicitly request stencil-aperture suppression for the default build. R304 remains DNP in the native schematic/PCB and BOM.
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

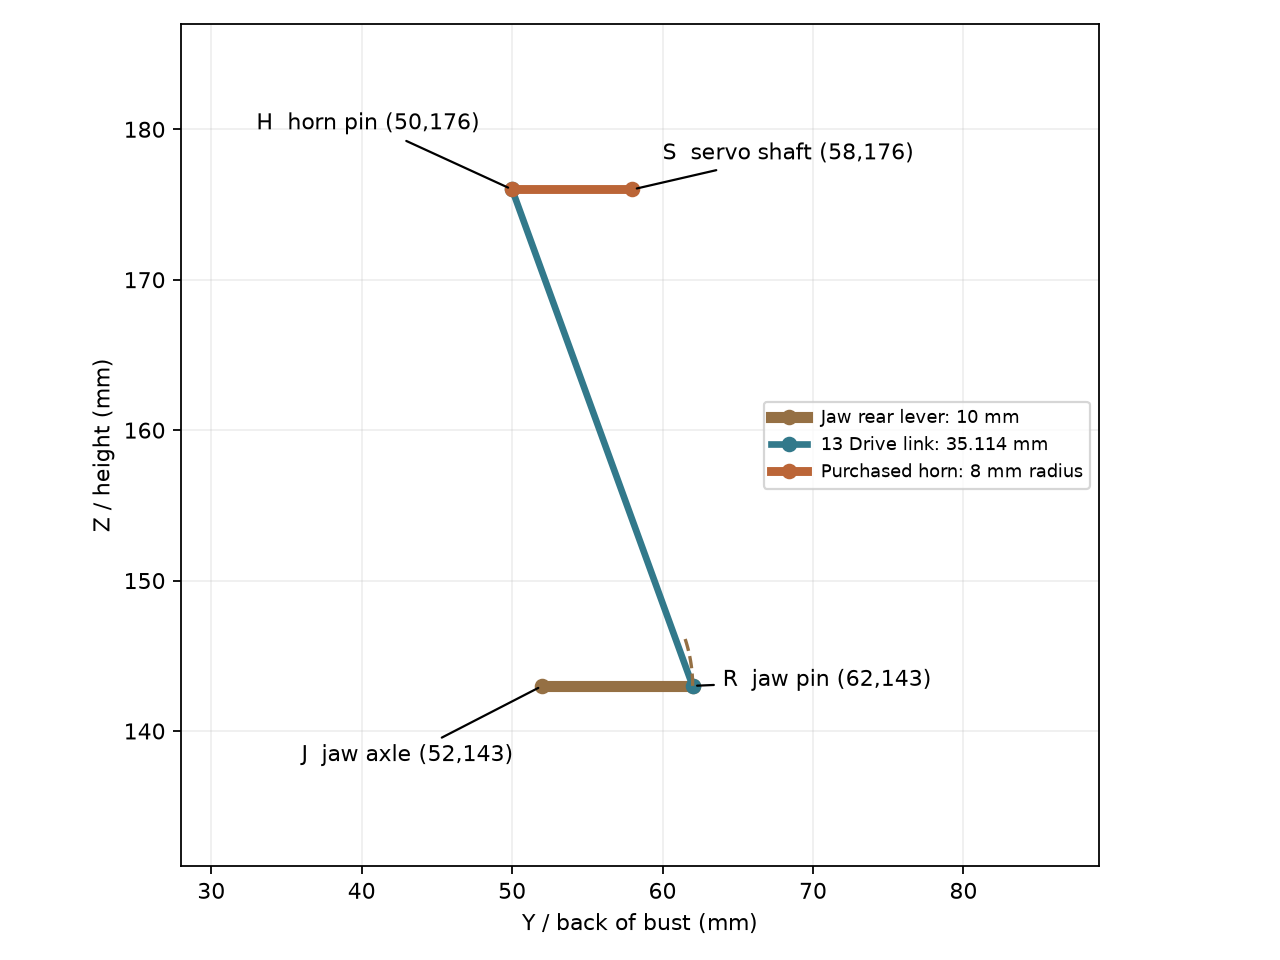
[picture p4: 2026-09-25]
hardware/cad/mechanical/rev-b/Jaw-schematic.png

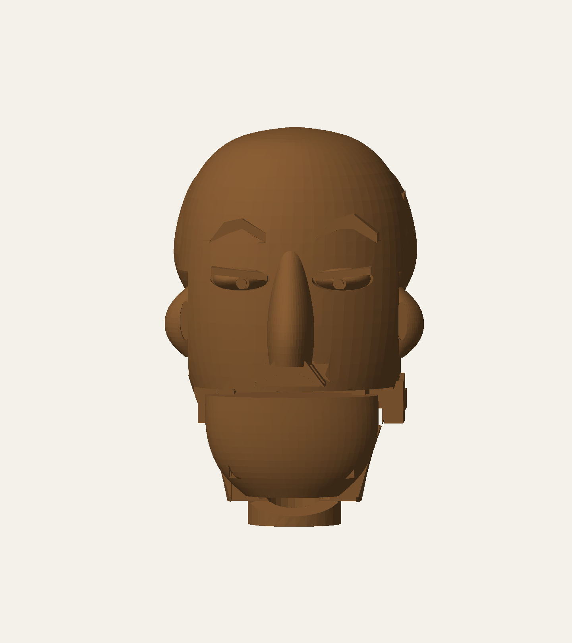
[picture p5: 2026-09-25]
hardware/cad/mechanical/rev-b/Alfred-face.png

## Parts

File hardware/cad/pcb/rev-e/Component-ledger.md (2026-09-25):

# Alfred revision E component ledger

The native schematic and PCB are authoritative. R304 is intentionally not fitted.

## J1 - USB-C 5V/5A PD
MPN: USB4105-GF-A. Footprint: Connector_USB:USB_C_Receptacle_GCT_USB4105-xx-A_16P_TopMnt_Horizontal.
Power-only input; integrated Rd in U1. All VBUS contacts connected.
Pins: A1=GND, A12=GND, B1=GND, B12=GND, SH=GND, A4=VBUS, A9=VBUS, B4=VBUS, B9=VBUS, A5=CC1, B5=CC2, A6=NC, A7=NC, A8=NC, B6=NC, B7=NC, B8=NC

## U1 - CYPD3177-24LQXQ
MPN: CYPD3177-24LQXQ. Footprint: Package_DFN_QFN:QFN-24-1EP_4x4mm_P0.5mm_EP2.75x2.75mm.
5 V min=max; coarse 5 A; fine 0 A. Standalone, no NVM programming.
Pins: 1=GND, 2=GND, 3=PD_GATE_DRV, 4=NC, 5=PD_3V3, 6=GND, 7=NC, 8=NC, 9=PD_FAULT, 10=PD_FLIP, 11=PD_5V, 12=NC, 13=NC, 14=CC2, 15=CC1, 16=NC, 17=NC, 18=VBUS, 19=GND, 20=NC, 21=NC, 22=GND, 23=PD_3V3, 24=PD_1V8, 25=GND

## Q1 - Si4459BDY
MPN: SI4459BDY-T1-GE3. Footprint: Package_SO:SO-8_3.9x4.9mm_P1.27mm.
30V SO8 PMOS; max 8.2 milliohm at VGS=-4.5V, 25C; lower input path drop than rev C.
Pins: 1=PFET_SOURCE, 2=PFET_SOURCE, 3=PFET_SOURCE, 4=PFET_GATE, 5=VBUS, 6=VBUS, 7=VBUS, 8=VBUS

## Q2 - Si4459BDY
MPN: SI4459BDY-T1-GE3. Footprint: Package_SO:SO-8_3.9x4.9mm_P1.27mm.
30V SO8 PMOS; max 8.2 milliohm at VGS=-4.5V, 25C; lower input path drop than rev C.
Pins: 1=PFET_SOURCE, 2=PFET_SOURCE, 3=PFET_SOURCE, 4=PFET_GATE, 5=PD_5V, 6=PD_5V, 7=PD_5V, 8=PD_5V

## R1 - 1k 1%
MPN: RC0805FR-071KL. Footprint: Resistor_SMD:R_0805_2012Metric.
Gate-driver isolation.
Pins: 1=PD_GATE_DRV, 2=PFET_GATE

## R2 - 100k 1%
MPN: RC0805FR-07100KL. Footprint: Resistor_SMD:R_0805_2012Metric.
Default gates off; 100k reduces loss of gate drive against driver pull-down resistance and shares an existing BOM value.
Pins: 1=PFET_SOURCE, 2=PFET_GATE

## R3 - 49.9k 1%
MPN: RC0805FR-0749K9L. Footprint: Resistor_SMD:R_0805_2012Metric.
Advertise no USB data capability; 49.9k nominal 50k.
Pins: 1=PD_3V3, 2=PD_FLIP

## R4 - 10k 1%
MPN: RC0805FR-0710KL. Footprint: Resistor_SMD:R_0805_2012Metric.
Input discharge/bleeder as reference design.
Pins: 1=VBUS, 2=GND

## D1 - 10V gate zener
MPN: BZT52C10-7-F. Footprint: Diode_SMD:D_SOD-123.
Limits magnitude of PMOS gate-source voltage.
Pins: 1=PFET_SOURCE, 2=PFET_GATE

## D2 - 15V transient suppressor
MPN: SMAJ15A-13-F. Footprint: Diode_SMD:D_SMA.
24.4 V maximum rated pulse clamp, below 28 V eFuse absolute maximum; not a sustained overvoltage absorber.
Pins: 1=VBUS, 2=GND

## C1 - 1u
MPN: C0805C105K5RACTU. Footprint: Capacitor_SMD:C_0805_2012Metric.
Input capacitance before controlled switch, 50 V.
Pins: 1=VBUS, 2=GND

## C2 - 1u
MPN: C0805C105K5RACTU. Footprint: Capacitor_SMD:C_0805_2012Metric.
Local decoupling; X7R unless noted.
Pins: 1=PD_3V3, 2=GND

## C3 - 100n
MPN: C0805C104K5RACTU. Footprint: Capacitor_SMD:C_0805_2012Metric.
Local decoupling; X7R unless noted.
Pins: 1=PD_3V3, 2=GND

## C4 - 100n
MPN: C0805C104K5RACTU. Footprint: Capacitor_SMD:C_0805_2012Metric.
Local decoupling; X7R unless noted.
Pins: 1=PD_3V3, 2=GND

## C5 - 1u
MPN: C0805C105K5RACTU. Footprint: Capacitor_SMD:C_0805_2012Metric.
Local decoupling; X7R unless noted.
Pins: 1=PD_1V8, 2=GND

## C6 - 1u
MPN: C0805C105K5RACTU. Footprint: Capacitor_SMD:C_0805_2012Metric.
Decoupling after PD FETs.
Pins: 1=PD_5V, 2=GND

## TP1 - VBUS
MPN: PCB copper test point. Footprint: TestPoint:TestPoint_Pad_D1.5mm.
Probe access; no purchased component
Pins: 1=VBUS

## TP2 - PD_5V
MPN: PCB copper test point. Footprint: TestPoint:TestPoint_Pad_D1.5mm.
Probe access; no purchased component
Pins: 1=PD_5V

## TP3 - PD_FAULT
MPN: PCB copper test point. Footprint: TestPoint:TestPoint_Pad_D1.5mm.
Probe access; no purchased component
Pins: 1=PD_FAULT

## TP4 - GND
MPN: PCB copper test point. Footprint: TestPoint:TestPoint_Pad_D1.5mm.
Probe access; no purchased component
Pins: 1=GND

## TP5 - PD_3V3
MPN: PCB copper test point. Footprint: TestPoint:TestPoint_Pad_D1.5mm.
Probe access; no purchased component
Pins: 1=PD_3V3

## TP6 - PD_1V8
MPN: PCB copper test point. Footprint: TestPoint:TestPoint_Pad_D1.5mm.
Probe access; no purchased component
Pins: 1=PD_1V8

## U2 - TPS259470LRPWR
MPN: TPS259470LRPWR. Footprint: Alfred:TI_RPW0010A.
Pi/audio protected rail, about2.02A nominal current limit, with slower startup for2200uF reservoir.
Pins: 1=PI_EN_UVLO, 2=PI_OV, 3=NC, 4=PI_FAULT_N, 5=PD_5V, 6=PI_5V, 7=PI_DVDT, 8=GND, 9=PI_ILM, 10=NC

## U3 - TPS259470LRPWR
MPN: TPS259470LRPWR. Footprint: Alfred:TI_RPW0010A.
Adjustable OVP, active current limit, thermal latch-off and reverse blocking; ITIMER open.
Pins: 1=SERVO_EN, 2=SERVO_OV, 3=NC, 4=SERVO_FAULT_N, 5=PD_5V, 6=SERVO_5V, 7=SERVO_DVDT, 8=GND, 9=SERVO_ILM, 10=NC

## R101 - 1.65k 0.1%
MPN: RT0805BRD071K65L. Footprint: Resistor_SMD:R_0805_2012Metric.
Pi/audio overcurrent setting about 2.02A nominal, 1.8-2.2A datasheet limits before resistor tolerance. Intended rail load <=1.65A.
Pins: 1=PI_ILM, 2=GND

## R102 - 3.32k 0.1%
MPN: RT0805BRD073K32L. Footprint: Resistor_SMD:R_0805_2012Metric.
3334/3320 = 1.004 A nominal; approx 0.85-1.15 A tolerance band.
Pins: 1=SERVO_ILM, 2=GND

## R103 - 34.0k 0.1%
MPN: RT0805BRD0734KL. Footprint: Resistor_SMD:R_0805_2012Metric.
1.2*(1+34/10)=5.28 V nominal overvoltage cutoff.
Pins: 1=PD_5V, 2=PI_OV

## R104 - 10k 0.1%
MPN: RT0805BRD0710KL. Footprint: Resistor_SMD:R_0805_2012Metric.
Precision OVP divider bottom.
Pins: 1=PI_OV, 2=GND

## R105 - 34.0k 0.1%
MPN: RT0805BRD0734KL. Footprint: Resistor_SMD:R_0805_2012Metric.
1.2*(1+34/10)=5.28 V nominal overvoltage cutoff.
Pins: 1=PD_5V, 2=SERVO_OV

## R106 - 10k 0.1%
MPN: RT0805BRD0710KL. Footprint: Resistor_SMD:R_0805_2012Metric.
Precision OVP divider bottom.
Pins: 1=SERVO_OV, 2=GND

## C101 - 10n
MPN: C0805C103J5GACTU. Footprint: Capacitor_SMD:C_0805_2012Metric.
Slows Pi/audio startup to about25.5ms nominal; reduces2200uF reservoir charging surge to about0.44A nominal.
Pins: 1=PI_DVDT, 2=GND

## C102 - 4.7n
MPN: C0805C472J5GACTU. Footprint: Capacitor_SMD:C_0805_2012Metric.
0.426 V/ms nominal slew; about 0.43 A capacitor charging current.
Pins: 1=SERVO_DVDT, 2=GND

## C103 - 100n
MPN: C0805C104K5RACTU. Footprint: Capacitor_SMD:C_0805_2012Metric.
U2 input bypass.
Pins: 1=PD_5V, 2=GND

## C104 - 100n
MPN: C0805C104K5RACTU. Footprint: Capacitor_SMD:C_0805_2012Metric.
U3 input bypass.
Pins: 1=PD_5V, 2=GND

## C105 - 2200u 10V
MPN: EEU-FR1A222L. Footprint: Capacitor_THT:CP_Radial_D10.0mm_P5.00mm.
Reverse-isolated Pi/audio reservoir; +/-20%; hand-solder after reflow.
Pins: 1=PI_5V, 2=GND

## C106 - 1000u 10V
MPN: EEU-FR1A102L. Footprint: Capacitor_THT:CP_Radial_D8.0mm_P3.50mm.
Servo reservoir; +/-20%; hand-solder after reflow.
Pins: 1=SERVO_5V, 2=GND

## C107 - 10u
MPN: C1206C106K4RACTU. Footprint: Capacitor_SMD:C_1206_3216Metric.
Local decoupling; X7R unless noted.
Pins: 1=PI_5V, 2=GND

## C108 - 10u
MPN: C1206C106K4RACTU. Footprint: Capacitor_SMD:C_1206_3216Metric.
Local decoupling; X7R unless noted.
Pins: 1=SERVO_5V, 2=GND

## U4 - TPS389001DSET
MPN: TPS389001DSET. Footprint: Package_SON:WSON-6_1.5x1.5mm_P0.5mm.
1% supervisor; nominal4.8300V falling and4.8594V rising;107ms nominal qualification and asynchronous arm-latch clear.
Pins: 1=UV_SENSE, 2=GND, 3=PI_3V3, 4=PI_3V3, 5=UV_DELAY, 6=SUPPLY_OK

## R107 - 32.0k 0.1%
MPN: RT0805BRD0732KL. Footprint: Resistor_SMD:R_0805_2012Metric.
Verified catalog 32k 0.1% supervisor top resistor; nominal fall 4.8300V, rise 4.8594V.
Pins: 1=PI_5V, 2=UV_SENSE

## R108 - 10k 0.1%
MPN: RT0805BRD0710KL. Footprint: Resistor_SMD:R_0805_2012Metric.
UV threshold divider bottom.
Pins: 1=UV_SENSE, 2=GND

## R109 - 2.2k 1%
MPN: RC0805FR-072K2L. Footprint: Resistor_SMD:R_0805_2012Metric.
Supervisor open-drain pullup; 1.5mA sink at3.3V, faster reset-release edge for AUP latch.
Pins: 1=SUPPLY_OK, 2=PI_3V3

## C109 - 100n
MPN: C0805C104K5RACTU. Footprint: Capacitor_SMD:C_0805_2012Metric.
Supervisor supply bypass.
Pins: 1=PI_3V3, 2=GND

## U5 - SN74LVC1G08DBVR
MPN: SN74LVC1G08DBVR. Footprint: Package_TO_SOT_SMD:SOT-23-5.
AND of hardware armed latch and software request; request low always disables power.
Pins: 1=SERVO_ARMED, 2=SERVO_REQUEST, 3=GND, 4=SERVO_EN, 5=PI_3V3

## R110 - 100k 1%
MPN: RC0805FR-07100KL. Footprint: Resistor_SMD:R_0805_2012Metric.
Keep motor supply off with Pi absent.
Pins: 1=SERVO_EN, 2=GND

## R111 - 100k 1%
MPN: RC0805FR-07100KL. Footprint: Resistor_SMD:R_0805_2012Metric.
Default off during boot.
Pins: 1=SERVO_REQUEST, 2=GND

## R112 - 10k 1%
MPN: RC0805FR-0710KL. Footprint: Resistor_SMD:R_0805_2012Metric.
Fault output pull-up.
Pins: 1=PI_3V3, 2=SERVO_FAULT_N

## R113 - 10k 1%
MPN: RC0805FR-0710KL. Footprint: Resistor_SMD:R_0805_2012Metric.
Fault output pull-up.
Pins: 1=PI_3V3, 2=PI_FAULT_N

## C110 - 100n
MPN: C0805C104K5RACTU. Footprint: Capacitor_SMD:C_0805_2012Metric.
AND gate bypass.
Pins: 1=PI_3V3, 2=GND

## C111 - 100n
MPN: C0805C104K5RACTU. Footprint: Capacitor_SMD:C_0805_2012Metric.
Supervisor reset-release delay about107ms nominal; delay qualification only, not fault detection delay.
Pins: 1=UV_DELAY, 2=GND

## TP101 - PI_5V
MPN: PCB copper test point. Footprint: TestPoint:TestPoint_Pad_D1.5mm.
Probe access; no purchased component
Pins: 1=PI_5V

## TP102 - SERVO_5V
MPN: PCB copper test point. Footprint: TestPoint:TestPoint_Pad_D1.5mm.
Probe access; no purchased component
Pins: 1=SERVO_5V

## TP103 - SUPPLY_OK
MPN: PCB copper test point. Footprint: TestPoint:TestPoint_Pad_D1.5mm.
Probe access; no purchased component
Pins: 1=SUPPLY_OK

## TP104 - SERVO_ILM
MPN: PCB copper test point. Footprint: TestPoint:TestPoint_Pad_D1.5mm.
Probe access; no purchased component
Pins: 1=SERVO_ILM

## TP105 - PI_FAULT_N
MPN: PCB copper test point. Footprint: TestPoint:TestPoint_Pad_D1.5mm.
Probe access; no purchased component
Pins: 1=PI_FAULT_N

## TP106 - GND
MPN: PCB copper test point. Footprint: TestPoint:TestPoint_Pad_D1.5mm.
Probe access; no purchased component
Pins: 1=GND

## J2 - Pi Zero 2 W carrier socket
MPN: SSW-120-01-G-D. Footprint: Connector_PinSocket_2.54mm:PinSocket_2x20_P2.54mm_Vertical.
Socket on carrier top; male header soldered on Pi underside; all grounds and both 5V pins used.
Pins: 1=PI_3V3, 2=PI_5V, 4=PI_5V, 11=AMP_ENABLE, 12=BCLK_PI, 13=SERVO_FAULT_N, 15=SERVO_REQUEST, 16=BUTTON_N, 18=LED_GPIO, 22=SUPPLY_OK, 32=JAW_PWM, 35=LRCLK_PI, 38=MIC_DATA_PI, 40=AMP_DATA_PI, 6=GND, 9=GND, 14=GND, 20=GND, 25=GND, 30=GND, 34=GND, 39=GND, 3=NC, 5=NC, 7=NC, 8=NC, 10=NC, 17=NC, 19=NC, 21=NC, 23=NC, 24=NC, 26=NC, 27=NC, 28=NC, 29=NC, 31=NC, 33=NC, 36=NC, 37=NC

## R201 - 33 1%
MPN: RC0805FR-0733RL. Footprint: Resistor_SMD:R_0805_2012Metric.
Source damping at Pi, shared clock.
Pins: 1=BCLK_PI, 2=BCLK

## R202 - 33 1%
MPN: RC0805FR-0733RL. Footprint: Resistor_SMD:R_0805_2012Metric.
Source damping at Pi, shared frame clock.
Pins: 1=LRCLK_PI, 2=LRCLK

## R203 - 33 1%
MPN: RC0805FR-0733RL. Footprint: Resistor_SMD:R_0805_2012Metric.
Source damping at Pi.
Pins: 1=AMP_DATA_PI, 2=AMP_DATA

## TP201 - PI_3V3
MPN: PCB copper test point. Footprint: TestPoint:TestPoint_Pad_D1.5mm.
Probe access; no purchased component
Pins: 1=PI_3V3

## TP202 - BCLK
MPN: PCB copper test point. Footprint: TestPoint:TestPoint_Pad_D1.5mm.
Probe access; no purchased component
Pins: 1=BCLK

## TP203 - LRCLK
MPN: PCB copper test point. Footprint: TestPoint:TestPoint_Pad_D1.5mm.
Probe access; no purchased component
Pins: 1=LRCLK

## TP204 - MIC_DATA_PI
MPN: PCB copper test point. Footprint: TestPoint:TestPoint_Pad_D1.5mm.
Probe access; no purchased component
Pins: 1=MIC_DATA_PI

## TP205 - GND
MPN: PCB copper test point. Footprint: TestPoint:TestPoint_Pad_D1.5mm.
Probe access; no purchased component
Pins: 1=GND

## U6 - ICS-43434
MPN: ICS-43434. Footprint: Sensor_Audio:InvenSense_ICS-43434-6_3.5x2.65mm.
Left slot selected. Bottom port through PCB; no paste/flux in port.
Pins: 1=LRCLK, 2=GND, 3=GND, 4=BCLK, 5=MIC_3V3, 6=MIC_DATA

## R301 - 47 1%
MPN: RC0805FR-0747RL. Footprint: Resistor_SMD:R_0805_2012Metric.
Quiet local mic supply; 550uA produces only 25.9mV drop.
Pins: 1=PI_3V3, 2=MIC_3V3

## C301 - 1u
MPN: C0805C105K5RACTU. Footprint: Capacitor_SMD:C_0805_2012Metric.
Mic RC supply filter.
Pins: 1=MIC_3V3, 2=GND

## C302 - 100n
MPN: C0805C104K5RACTU. Footprint: Capacitor_SMD:C_0805_2012Metric.
Mic immediate bypass.
Pins: 1=MIC_3V3, 2=GND

## R302 - 33 1%
MPN: RC0805FR-0733RL. Footprint: Resistor_SMD:R_0805_2012Metric.
Source termination at microphone.
Pins: 1=MIC_DATA, 2=MIC_DATA_PI

## R303 - 100k 1%
MPN: RC0805FR-07100KL. Footprint: Resistor_SMD:R_0805_2012Metric.
Defined data level during microphone tri-state slot.
Pins: 1=MIC_DATA_PI, 2=GND

## U7 - MAX98357AETE+T
MPN: MAX98357AETE+T. Footprint: Package_DFN_QFN:TQFN-16-1EP_3x3mm_P0.5mm_EP1.23x1.23mm.
Mono bridge amplifier; A=I2S; EP grounded; both speaker leads driven.
Pins: 1=AMP_DATA, 2=AMP_GAIN, 3=GND, 4=AMP_SD, 5=NC, 6=NC, 7=PI_5V, 8=PI_5V, 9=AMP_P, 10=AMP_N, 11=GND, 12=NC, 13=NC, 14=LRCLK, 15=GND, 16=BCLK, 17=GND

## R304 - 100k 1%
MPN: RC0805FR-07100KL. Footprint: Alfred:R_0805_DNP_NoPaste.
DO NOT FIT in revision E: floating GAIN_SLOT selects 9 dB. Optional 100k to VDD selects quiet 3 dB mode.
Pins: 1=AMP_GAIN, 2=PI_5V

## R305 - 1k 1%
MPN: RC0805FR-071KL. Footprint: Resistor_SMD:R_0805_2012Metric.
SD_MODE drive isolation; high selects left channel.
Pins: 1=AMP_ENABLE, 2=AMP_SD

## R306 - 100k 1%
MPN: RC0805FR-07100KL. Footprint: Resistor_SMD:R_0805_2012Metric.
Mute through boot; software enables after valid clocks.
Pins: 1=AMP_SD, 2=GND

## C303 - 100n
MPN: C0805C104K5RACTU. Footprint: Capacitor_SMD:C_0805_2012Metric.
At amplifier supply pins.
Pins: 1=PI_5V, 2=GND

## C304 - 10u
MPN: C1206C106K4RACTU. Footprint: Capacitor_SMD:C_1206_3216Metric.
At amplifier supply pins.
Pins: 1=PI_5V, 2=GND

## C305 - 100u 10V
MPN: EEU-FR1A101. Footprint: Capacitor_THT:CP_Radial_D5.0mm_P2.00mm.
Local amplifier bulk.
Pins: 1=PI_5V, 2=GND

## L1 - 10uH 3.2A
MPN: SRN6045TA-100M. Footprint: Alfred:SRN6045TA_100M.
Symmetric output LC; 4.6A saturation, DCR 52mOhm maximum; 6x6mm body.
Pins: 1=AMP_P, 2=SPK_P

## L2 - 10uH 3.2A
MPN: SRN6045TA-100M. Footprint: Alfred:SRN6045TA_100M.
Symmetric output LC; 4.6A saturation, DCR 52mOhm maximum; 6x6mm body.
Pins: 1=AMP_N, 2=SPK_N

## C306 - 220n
MPN: C0805C224K5RACTU. Footprint: Capacitor_SMD:C_0805_2012Metric.
Differential output filter; 20uH total gives 75.9kHz resonance.
Pins: 1=SPK_P, 2=SPK_N

## C307 - 1n
MPN: C0805C102J5GACTU. Footprint: Capacitor_SMD:C_0805_2012Metric.
C0G 50V, post-inductor common-mode EMI shunt.
Pins: 1=SPK_P, 2=GND

## C308 - 1n
MPN: C0805C102J5GACTU. Footprint: Capacitor_SMD:C_0805_2012Metric.
Matched C0G 50V, post-inductor EMI shunt.
Pins: 1=SPK_N, 2=GND

## J3 - Speaker 4ohm 3W
MPN: 282834-2. Footprint: TerminalBlock_TE-Connectivity:TerminalBlock_TE_282834-2_1x02_P2.54mm_Horizontal.
Screw terminal for bare speaker wires; neither terminal is ground.
Pins: 1=SPK_P, 2=SPK_N

## TP301 - MIC_3V3
MPN: PCB copper test point. Footprint: TestPoint:TestPoint_Pad_D1.5mm.
Probe access; no purchased component
Pins: 1=MIC_3V3

## TP302 - PI_5V
MPN: PCB copper test point. Footprint: TestPoint:TestPoint_Pad_D1.5mm.
Probe access; no purchased component
Pins: 1=PI_5V

## TP303 - GND
MPN: PCB copper test point. Footprint: TestPoint:TestPoint_Pad_D1.5mm.
Probe access; no purchased component
Pins: 1=GND

## U8 - SN74LVC1G07DBVR
MPN: SN74LVC1G07DBVR. Footprint: Package_TO_SOT_SMD:SOT-23-5.
5.5V-tolerant open drain and Ioff isolate Pi from connector +5V faults.
Pins: 1=NC, 2=JAW_PWM, 3=GND, 4=JAW_OD, 5=PI_3V3

## R401 - 100k 1%
MPN: RC0805FR-07100KL. Footprint: Resistor_SMD:R_0805_2012Metric.
Boot-low PWM.
Pins: 1=JAW_PWM, 2=GND

## R402 - 4.7k 1%
MPN: RC0805FR-074K7L. Footprint: Resistor_SMD:R_0805_2012Metric.
5V signal pull-up before protective series resistor.
Pins: 1=SERVO_5V, 2=JAW_OD

## R403 - 1k 1%
MPN: RC0805FR-071KL. Footprint: Resistor_SMD:R_0805_2012Metric.
A short to +5V sinks at most about 5.3mA; ground short limited by pull-up.
Pins: 1=JAW_OD, 2=JAW_SIG

## C401 - 100n
MPN: C0805C104K5RACTU. Footprint: Capacitor_SMD:C_0805_2012Metric.
Buffer bypass.
Pins: 1=PI_3V3, 2=GND

## J4 - Jaw: GND +5V SIG
MPN: TSW-103-07-G-S. Footprint: Connector_PinHeader_2.54mm:PinHeader_1x03_P2.54mm_Vertical.
Standard servo plug; clearly mark both sides; retention clip recommended.
Pins: 1=GND, 2=SERVO_5V, 3=JAW_SIG

## U9 - TL431AIDBZR
MPN: TL431AIDBZR. Footprint: Package_TO_SOT_SMD:SOT-23.
Reference controls regenerative shunt. Verify dynamic stability with actual servo.
Pins: 1=REGEN_K, 2=REGEN_REF, 3=GND

## R404 - 12.4k 0.1%
MPN: RT0805BRD0712K4L. Footprint: Resistor_SMD:R_0805_2012Metric.
2.495*(1+12.4/10)=5.589V nominal dump threshold.
Pins: 1=SERVO_5V, 2=REGEN_REF

## R405 - 10k 0.1%
MPN: RT0805BRD0710KL. Footprint: Resistor_SMD:R_0805_2012Metric.
Shunt reference bottom.
Pins: 1=REGEN_REF, 2=GND

## R406 - 2.2k 1%
MPN: RC0805FR-072K2L. Footprint: Resistor_SMD:R_0805_2012Metric.
Cathode bias and gate pull-up, ~1.4mA at clamp onset.
Pins: 1=SERVO_5V, 2=REGEN_K

## R407 - 100 1%
MPN: RC0805FR-07100RL. Footprint: Resistor_SMD:R_0805_2012Metric.
Isolate capacitive FET gate.
Pins: 1=REGEN_K, 2=REGEN_GATE

## Q3 - AO3401A
MPN: AO3401A. Footprint: Package_TO_SOT_SMD:SOT-23.
PMOS shunts excess servo rail energy into R408.
Pins: 1=REGEN_GATE, 2=SERVO_5V, 3=DUMP

## R408 - 10ohm 5W
MPN: SQP500JB-10R. Footprint: Resistor_THT:R_Axial_Power_L25.0mm_W9.0mm_P30.48mm.
At 5.6V absorbs up to 3.14W. Mount 5mm above PCB, away from plastic.
Pins: 1=DUMP, 2=GND

## SW1 - Momentary button
MPN: B3F-1000. Footprint: Button_Switch_THT:SW_PUSH_6mm_H4.3mm.
Normally-open, front plunger access. No identity semantics.
Pins: 1=BUTTON_SWITCH, 2=GND

## R409 - 1k 1%
MPN: RC0805FR-071KL. Footprint: Resistor_SMD:R_0805_2012Metric.
Limits switch discharge current.
Pins: 1=BUTTON_SWITCH, 2=BUTTON_RC

## R410 - 100k 1%
MPN: RC0805FR-07100KL. Footprint: Resistor_SMD:R_0805_2012Metric.
Release RC time constant 10ms.
Pins: 1=PI_3V3, 2=BUTTON_RC

## C402 - 100n
MPN: C0805C104K5RACTU. Footprint: Capacitor_SMD:C_0805_2012Metric.
Press time constant ~0.1ms; software requires 30ms stable both edges.
Pins: 1=BUTTON_RC, 2=GND

## U10 - SN74LVC1G17DBVR
MPN: SN74LVC1G17DBVR. Footprint: Package_TO_SOT_SMD:SOT-23-5.
Schmitt buffer converts slow RC edges to clean logic.
Pins: 1=NC, 2=BUTTON_RC, 3=GND, 4=BUTTON_N, 5=PI_3V3

## C403 - 100n
MPN: C0805C104K5RACTU. Footprint: Capacitor_SMD:C_0805_2012Metric.
Schmitt buffer bypass.
Pins: 1=PI_3V3, 2=GND

## R411 - 680 1%
MPN: RC0805FR-07680RL. Footprint: Resistor_SMD:R_0805_2012Metric.
About 2mA for green LED Vf~2V.
Pins: 1=LED_GPIO, 2=LED_A

## D3 - Green status LED
MPN: WP710A10SGC. Footprint: LED_THT:LED_D3.0mm.
Visible via printed light pipe.
Pins: 1=GND, 2=LED_A

## TP401 - JAW_SIG
MPN: PCB copper test point. Footprint: TestPoint:TestPoint_Pad_D1.5mm.
Probe access; no purchased component
Pins: 1=JAW_SIG

## TP402 - SERVO_EN
MPN: PCB copper test point. Footprint: TestPoint:TestPoint_Pad_D1.5mm.
Probe access; no purchased component
Pins: 1=SERVO_EN

## TP403 - BUTTON_N
MPN: PCB copper test point. Footprint: TestPoint:TestPoint_Pad_D1.5mm.
Probe access; no purchased component
Pins: 1=BUTTON_N

## TP404 - GND
MPN: PCB copper test point. Footprint: TestPoint:TestPoint_Pad_D1.5mm.
Probe access; no purchased component
Pins: 1=GND

## R114 - 10k 1%
MPN: RC0805FR-0710KL. Footprint: Resistor_SMD:R_0805_2012Metric.
10k/10k EN divider; 2.55 V nominal at 5.1 V input, with D101 fault clamp.
Pins: 1=PD_5V, 2=PI_EN_UVLO

## R115 - 10k 1%
MPN: RC0805FR-0710KL. Footprint: Resistor_SMD:R_0805_2012Metric.
10k/10k EN divider; 2.55 V nominal at 5.1 V input, with D101 fault clamp.
Pins: 1=PI_EN_UVLO, 2=GND

## D101 - 5.1V EN clamp
MPN: MMSZ5V1T1G. Footprint: Diode_SMD:D_SOD-123.
Cathode to EN, anode to ground. Limits EN fault voltage; R114 limits clamp current.
Pins: 1=PI_EN_UVLO, 2=GND

## U11 - 74AUP1G74DC
MPN: 74AUP1G74DC,125. Footprint: Package_SO:VSSOP-8_2.3x2mm_P0.5mm.
Schmitt-input arm latch; active-low supply-good clears Q asynchronously. New request rising edge required after recovery. Nexperia AUP part, 3.3V only.
Pins: 1=SERVO_REQUEST, 2=PI_3V3, 3=NC, 4=GND, 5=SERVO_ARMED, 6=SUPPLY_OK, 7=PI_3V3, 8=PI_3V3

## C112 - 100n
MPN: C0805C104K5RACTU. Footprint: Capacitor_SMD:C_0805_2012Metric.
Local bypass for U11 arm latch.
Pins: 1=PI_3V3, 2=GND

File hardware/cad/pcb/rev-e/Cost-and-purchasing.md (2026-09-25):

# Revision E cost status

Purchasing is deferred at the user request. The PCB component allowance is $43.70, a mixed estimate rather than a current quote. No active devices or additional placements were added; three existing passive values changed. The external BOM now includes the Pi, microSD, custom mechanics, stencil and assembly as unpriced requirements. The previous $99.06 total excluded required items and must not be used as a complete build price.

The microphone lifecycle, speaker availability and all supplier pricing remain for the later purchasing pass. R107, R101 and C101 have verified catalog identities. Adafruit 4445 remains the drawing's speaker; Adafruit 3351 is a possible separately documented alternative requiring lead adaptation and a fit check. Do not silently substitute it in assembly.

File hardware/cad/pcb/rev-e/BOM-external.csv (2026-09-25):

Item | Quantity | Specification | Budget allowance USD | Supplier | URL
Jaw servo | 1 | FEETECH FS90 / Pololu 2818 | 8.4 | Pololu | https://www.pololu.com/product/2818
Speaker | 1 | Adafruit 4445, 4 ohm 3 W enclosed | 3.95 | Adafruit | https://www.adafruit.com/product/4445
Power supply | 1 | Raspberry Pi 27 W USB-C, US plug | 12 | Pi authorized reseller | https://www.raspberrypi.com/products/27w-power-supply/
Pi male header | 1 | Samtec TSW-120-07-G-D | 3 | DigiKey
Carrier PCB | 1 | 120 x 94 mm, 4 layers, 1.6 mm, 35 um finished copper on ALL four layers; quote required | 20 | Fabricator quote required
Mechanical hardware and wire | 1 | M3 carrier / M2.5 Pi supports, shims, wire, gasket | 8 | Local stock / distributor
Raspberry Pi | 1 | Raspberry Pi Zero 2 W, GPIO header unsoldered; mount specified male header on underside |  | Deferred
microSD card | 1 | 32GB or larger compatible card; Raspberry Pi OS; reader needed for flashing if not already available |  | Deferred
Enclosure and jaw linkage | 1 | Printed housing, speaker cradle, microphone gasket/duct and calibrated servo linkage per mechanical drawings |  | Custom fabrication
Stencil and assembly | 1 | 0.10mm stencil, SMT reflow and through-hole assembly per fabrication instructions |  | Quote deferred

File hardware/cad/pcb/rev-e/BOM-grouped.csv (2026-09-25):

References fitted | Quantity fitted per board | Lean purchase quantity for ONE board | Optional purchase with small-passive spares | MPN | Value | Footprint | Unit USD allowance - NOT QUOTE | Lean extended USD allowance | Price evidence
J3 | 1 | 1 | 1 | 282834-2 | Speaker 4ohm 3W | TerminalBlock_TE-Connectivity:TerminalBlock_TE_282834-2_1x02_P2.54mm_Horizontal | 0.8 | 0.8 | Inherited allowance; refresh supplier cart
U11 | 1 | 1 | 1 | 74AUP1G74DC,125 | 74AUP1G74DC | Package_SO:VSSOP-8_2.3x2mm_P0.5mm | 0.46 | 0.46 | Inherited allowance; refresh supplier cart
Q3 | 1 | 1 | 1 | AO3401A | AO3401A | Package_TO_SOT_SMD:SOT-23 | 0.25 | 0.25 | Inherited allowance; refresh supplier cart
SW1 | 1 | 1 | 1 | B3F-1000 | Momentary button | Button_Switch_THT:SW_PUSH_6mm_H4.3mm | 0.3 | 0.3 | Inherited allowance; refresh supplier cart
D1 | 1 | 1 | 1 | BZT52C10-7-F | 10V gate zener | Diode_SMD:D_SOD-123 | 0.12 | 0.12 | Inherited allowance; refresh supplier cart
C307, C308 | 2 | 2 | 4 | C0805C102J5GACTU | 1n | Capacitor_SMD:C_0805_2012Metric | 0.15 | 0.3 | Inherited allowance; refresh supplier cart
C101 | 1 | 1 | 1 | C0805C103J5GACTU | 10n | Capacitor_SMD:C_0805_2012Metric | 0.3 | 0.3 | Inherited allowance; refresh supplier cart
C3, C4, C103, C104, C109, C110, C111, C302, C303, C401, C402, C403, C112 | 13 | 13 | 15 | C0805C104K5RACTU | 100n | Capacitor_SMD:C_0805_2012Metric | 0.15 | 1.95 | Inherited allowance; refresh supplier cart
C1, C2, C5, C6, C301 | 5 | 5 | 7 | C0805C105K5RACTU | 1u | Capacitor_SMD:C_0805_2012Metric | 0.15 | 0.75 | Inherited allowance; refresh supplier cart
C306 | 1 | 1 | 3 | C0805C224K5RACTU | 220n | Capacitor_SMD:C_0805_2012Metric | 0.15 | 0.15 | Inherited allowance; refresh supplier cart
C102 | 1 | 1 | 3 | C0805C472J5GACTU | 4.7n | Capacitor_SMD:C_0805_2012Metric | 0.15 | 0.15 | Inherited allowance; refresh supplier cart
C107, C108, C304 | 3 | 3 | 5 | C1206C106K4RACTU | 10u | Capacitor_SMD:C_1206_3216Metric | 0.15 | 0.45 | Inherited allowance; refresh supplier cart
U1 | 1 | 1 | 1 | CYPD3177-24LQXQ | CYPD3177-24LQXQ | Package_DFN_QFN:QFN-24-1EP_4x4mm_P0.5mm_EP2.75x2.75mm | 3.5 | 3.5 | Inherited allowance; refresh supplier cart
C305 | 1 | 1 | 1 | EEU-FR1A101 | 100u 10V | Capacitor_THT:CP_Radial_D5.0mm_P2.00mm | 0.35 | 0.35 | Inherited allowance; refresh supplier cart
C106 | 1 | 1 | 1 | EEU-FR1A102L | 1000u 10V | Capacitor_THT:CP_Radial_D8.0mm_P3.50mm | 0.85 | 0.85 | Inherited allowance; refresh supplier cart
C105 | 1 | 1 | 1 | EEU-FR1A222L | 2200u 10V | Capacitor_THT:CP_Radial_D10.0mm_P5.00mm | 1.3 | 1.3 | Inherited allowance; refresh supplier cart
U6 | 1 | 1 | 1 | ICS-43434 | ICS-43434 | Sensor_Audio:InvenSense_ICS-43434-6_3.5x2.65mm | 4.2 | 4.2 | Inherited allowance; refresh supplier cart
U7 | 1 | 1 | 1 | MAX98357AETE+T | MAX98357AETE+T | Package_DFN_QFN:TQFN-16-1EP_3x3mm_P0.5mm_EP1.23x1.23mm | 4.08 | 4.08 | Inherited allowance; refresh supplier cart
D101 | 1 | 1 | 1 | MMSZ5V1T1G | 5.1V EN clamp | Diode_SMD:D_SOD-123 | 0.17 | 0.17 | DigiKey indexed substitute listing: $0.17, 101196 in stock, checked 2026-09-10; not reserved
R2, R110, R111, R303, R306, R401, R410 | 7 | 7 | 9 | RC0805FR-07100KL | 100k 1% | Resistor_SMD:R_0805_2012Metric | 0.05 | 0.35 | Inherited allowance; refresh supplier cart
R407 | 1 | 1 | 3 | RC0805FR-07100RL | 100 1% | Resistor_SMD:R_0805_2012Metric | 0.05 | 0.05 | Inherited allowance; refresh supplier cart
R4, R112, R113, R114, R115 | 5 | 5 | 7 | RC0805FR-0710KL | 10k 1% | Resistor_SMD:R_0805_2012Metric | 0.05 | 0.25 | Inherited allowance; refresh supplier cart
R1, R305, R403, R409 | 4 | 4 | 6 | RC0805FR-071KL | 1k 1% | Resistor_SMD:R_0805_2012Metric | 0.05 | 0.2 | Inherited allowance; refresh supplier cart
R109, R406 | 2 | 2 | 4 | RC0805FR-072K2L | 2.2k 1% | Resistor_SMD:R_0805_2012Metric | 0.05 | 0.1 | Inherited allowance; refresh supplier cart
R201, R202, R203, R302 | 4 | 4 | 6 | RC0805FR-0733RL | 33 1% | Resistor_SMD:R_0805_2012Metric | 0.05 | 0.2 | Inherited allowance; refresh supplier cart
R301 | 1 | 1 | 3 | RC0805FR-0747RL | 47 1% | Resistor_SMD:R_0805_2012Metric | 0.05 | 0.05 | Inherited allowance; refresh supplier cart
R3 | 1 | 1 | 3 | RC0805FR-0749K9L | 49.9k 1% | Resistor_SMD:R_0805_2012Metric | 0.05 | 0.05 | Inherited allowance; refresh supplier cart
R402 | 1 | 1 | 3 | RC0805FR-074K7L | 4.7k 1% | Resistor_SMD:R_0805_2012Metric | 0.05 | 0.05 | Inherited allowance; refresh supplier cart
R411 | 1 | 1 | 3 | RC0805FR-07680RL | 680 1% | Resistor_SMD:R_0805_2012Metric | 0.05 | 0.05 | Inherited allowance; refresh supplier cart
R104, R106, R108, R405 | 4 | 4 | 6 | RT0805BRD0710KL | 10k 0.1% | Resistor_SMD:R_0805_2012Metric | 0.18 | 0.72 | Inherited allowance; refresh supplier cart
R404 | 1 | 1 | 3 | RT0805BRD0712K4L | 12.4k 0.1% | Resistor_SMD:R_0805_2012Metric | 0.18 | 0.18 | Inherited allowance; refresh supplier cart
R101 | 1 | 1 | 3 | RT0805BRD071K65L | 1.65k 0.1% | Resistor_SMD:R_0805_2012Metric | 0.1 | 0.1 | Inherited allowance; refresh supplier cart
R107 | 1 | 1 | 3 | RT0805BRD0732KL | 32.0k 0.1% | Resistor_SMD:R_0805_2012Metric | 0.1 | 0.1 | Inherited allowance; refresh supplier cart
R103, R105 | 2 | 2 | 4 | RT0805BRD0734KL | 34.0k 0.1% | Resistor_SMD:R_0805_2012Metric | 0.18 | 0.36 | Inherited allowance; refresh supplier cart
R102 | 1 | 1 | 3 | RT0805BRD073K32L | 3.32k 0.1% | Resistor_SMD:R_0805_2012Metric | 0.18 | 0.18 | Inherited allowance; refresh supplier cart
Q1, Q2 | 2 | 2 | 2 | SI4459BDY-T1-GE3 | Si4459BDY | Package_SO:SO-8_3.9x4.9mm_P1.27mm | 2.06 | 4.12 | Inherited allowance; refresh supplier cart
D2 | 1 | 1 | 1 | SMAJ15A-13-F | 15V transient suppressor | Diode_SMD:D_SMA | 0.45 | 0.45 | Inherited allowance; refresh supplier cart
U8 | 1 | 1 | 1 | SN74LVC1G07DBVR | SN74LVC1G07DBVR | Package_TO_SOT_SMD:SOT-23-5 | 0.35 | 0.35 | Inherited allowance; refresh supplier cart
U5 | 1 | 1 | 1 | SN74LVC1G08DBVR | SN74LVC1G08DBVR | Package_TO_SOT_SMD:SOT-23-5 | 0.35 | 0.35 | Inherited allowance; refresh supplier cart
U10 | 1 | 1 | 1 | SN74LVC1G17DBVR | SN74LVC1G17DBVR | Package_TO_SOT_SMD:SOT-23-5 | 0.4 | 0.4 | Inherited allowance; refresh supplier cart
R408 | 1 | 1 | 1 | SQP500JB-10R | 10ohm 5W | Resistor_THT:R_Axial_Power_L25.0mm_W9.0mm_P30.48mm | 0.6 | 0.6 | Inherited allowance; refresh supplier cart
L1, L2 | 2 | 2 | 2 | SRN6045TA-100M | 10uH 3.2A | Alfred:SRN6045TA_100M | 0.75 | 1.5 | Inherited allowance; refresh supplier cart
J2 | 1 | 1 | 1 | SSW-120-01-G-D | Pi Zero 2 W carrier socket | Connector_PinSocket_2.54mm:PinSocket_2x20_P2.54mm_Vertical | 4.5 | 4.5 | Inherited allowance; refresh supplier cart
U9 | 1 | 1 | 1 | TL431AIDBZR | TL431AIDBZR | Package_TO_SOT_SMD:SOT-23 | 0.4 | 0.4 | Inherited allowance; refresh supplier cart
U2, U3 | 2 | 2 | 2 | TPS259470LRPWR | TPS259470LRPWR | Alfred:TI_RPW0010A | 1.72 | 3.44 | Inherited allowance; refresh supplier cart
U4 | 1 | 1 | 1 | TPS389001DSET | TPS389001DSET | Package_SON:WSON-6_1.5x1.5mm_P0.5mm | 2.22 | 2.22 | Inherited allowance; refresh supplier cart
J4 | 1 | 1 | 1 | TSW-103-07-G-S | Jaw: GND +5V SIG | Connector_PinHeader_2.54mm:PinHeader_1x03_P2.54mm_Vertical | 0.45 | 0.45 | Inherited allowance; refresh supplier cart
J1 | 1 | 1 | 1 | USB4105-GF-A | USB-C 5V/5A PD | Connector_USB:USB_C_Receptacle_GCT_USB4105-xx-A_16P_TopMnt_Horizontal | 1.2 | 1.2 | Inherited allowance; refresh supplier cart
D3 | 1 | 1 | 1 | WP710A10SGC | Green status LED | LED_THT:LED_D3.0mm | 0.3 | 0.3 | Inherited allowance; refresh supplier cart

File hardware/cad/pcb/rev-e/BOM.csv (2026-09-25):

Reference | Fitted quantity | Value | Manufacturer part number | KiCad footprint | Unit USD allowance - NOT QUOTE | Assembly | Purpose
J1 | 1 | USB-C 5V/5A PD | USB4105-GF-A | Connector_USB:USB_C_Receptacle_GCT_USB4105-xx-A_16P_TopMnt_Horizontal | 1.2 | FIT | Power-only input; integrated Rd in U1. All VBUS contacts connected.
U1 | 1 | CYPD3177-24LQXQ | CYPD3177-24LQXQ | Package_DFN_QFN:QFN-24-1EP_4x4mm_P0.5mm_EP2.75x2.75mm | 3.5 | FIT | 5 V min=max; coarse 5 A; fine 0 A. Standalone, no NVM programming.
Q1 | 1 | Si4459BDY | SI4459BDY-T1-GE3 | Package_SO:SO-8_3.9x4.9mm_P1.27mm | 2.06 | FIT | 30V SO8 PMOS; max 8.2 milliohm at VGS=-4.5V, 25C; lower input path drop than rev C.
Q2 | 1 | Si4459BDY | SI4459BDY-T1-GE3 | Package_SO:SO-8_3.9x4.9mm_P1.27mm | 2.06 | FIT | 30V SO8 PMOS; max 8.2 milliohm at VGS=-4.5V, 25C; lower input path drop than rev C.
R1 | 1 | 1k 1% | RC0805FR-071KL | Resistor_SMD:R_0805_2012Metric | 0.05 | FIT | Gate-driver isolation.
R2 | 1 | 100k 1% | RC0805FR-07100KL | Resistor_SMD:R_0805_2012Metric | 0.05 | FIT | Default gates off; 100k reduces loss of gate drive against driver pull-down resistance and shares an existing BOM value.
R3 | 1 | 49.9k 1% | RC0805FR-0749K9L | Resistor_SMD:R_0805_2012Metric | 0.05 | FIT | Advertise no USB data capability; 49.9k nominal 50k.
R4 | 1 | 10k 1% | RC0805FR-0710KL | Resistor_SMD:R_0805_2012Metric | 0.05 | FIT | Input discharge/bleeder as reference design.
D1 | 1 | 10V gate zener | BZT52C10-7-F | Diode_SMD:D_SOD-123 | 0.12 | FIT | Limits magnitude of PMOS gate-source voltage.
D2 | 1 | 15V transient suppressor | SMAJ15A-13-F | Diode_SMD:D_SMA | 0.45 | FIT | 24.4 V maximum rated pulse clamp, below 28 V eFuse absolute maximum; not a sustained overvoltage absorber.
C1 | 1 | 1u | C0805C105K5RACTU | Capacitor_SMD:C_0805_2012Metric | 0.15 | FIT | Input capacitance before controlled switch, 50 V.
C2 | 1 | 1u | C0805C105K5RACTU | Capacitor_SMD:C_0805_2012Metric | 0.15 | FIT | Local decoupling; X7R unless noted.
C3 | 1 | 100n | C0805C104K5RACTU | Capacitor_SMD:C_0805_2012Metric | 0.15 | FIT | Local decoupling; X7R unless noted.
C4 | 1 | 100n | C0805C104K5RACTU | Capacitor_SMD:C_0805_2012Metric | 0.15 | FIT | Local decoupling; X7R unless noted.
C5 | 1 | 1u | C0805C105K5RACTU | Capacitor_SMD:C_0805_2012Metric | 0.15 | FIT | Local decoupling; X7R unless noted.
C6 | 1 | 1u | C0805C105K5RACTU | Capacitor_SMD:C_0805_2012Metric | 0.15 | FIT | Decoupling after PD FETs.
TP1 | 0 | VBUS | PCB copper test point | TestPoint:TestPoint_Pad_D1.5mm | 0 | PCB feature | Probe access; no purchased component
TP2 | 0 | PD_5V | PCB copper test point | TestPoint:TestPoint_Pad_D1.5mm | 0 | PCB feature | Probe access; no purchased component
TP3 | 0 | PD_FAULT | PCB copper test point | TestPoint:TestPoint_Pad_D1.5mm | 0 | PCB feature | Probe access; no purchased component
TP4 | 0 | GND | PCB copper test point | TestPoint:TestPoint_Pad_D1.5mm | 0 | PCB feature | Probe access; no purchased component
TP5 | 0 | PD_3V3 | PCB copper test point | TestPoint:TestPoint_Pad_D1.5mm | 0 | PCB feature | Probe access; no purchased component
TP6 | 0 | PD_1V8 | PCB copper test point | TestPoint:TestPoint_Pad_D1.5mm | 0 | PCB feature | Probe access; no purchased component
U2 | 1 | TPS259470LRPWR | TPS259470LRPWR | Alfred:TI_RPW0010A | 1.72 | FIT | Pi/audio protected rail, about2.02A nominal current limit, with slower startup for2200uF reservoir.
U3 | 1 | TPS259470LRPWR | TPS259470LRPWR | Alfred:TI_RPW0010A | 1.72 | FIT | Adjustable OVP, active current limit, thermal latch-off and reverse blocking; ITIMER open.
R101 | 1 | 1.65k 0.1% | RT0805BRD071K65L | Resistor_SMD:R_0805_2012Metric | 0.1 | FIT | Pi/audio overcurrent setting about 2.02A nominal, 1.8-2.2A datasheet limits before resistor tolerance. Intended rail load <=1.65A.
R102 | 1 | 3.32k 0.1% | RT0805BRD073K32L | Resistor_SMD:R_0805_2012Metric | 0.18 | FIT | 3334/3320 = 1.004 A nominal; approx 0.85-1.15 A tolerance band.
R103 | 1 | 34.0k 0.1% | RT0805BRD0734KL | Resistor_SMD:R_0805_2012Metric | 0.18 | FIT | 1.2*(1+34/10)=5.28 V nominal overvoltage cutoff.
R104 | 1 | 10k 0.1% | RT0805BRD0710KL | Resistor_SMD:R_0805_2012Metric | 0.18 | FIT | Precision OVP divider bottom.
R105 | 1 | 34.0k 0.1% | RT0805BRD0734KL | Resistor_SMD:R_0805_2012Metric | 0.18 | FIT | 1.2*(1+34/10)=5.28 V nominal overvoltage cutoff.
R106 | 1 | 10k 0.1% | RT0805BRD0710KL | Resistor_SMD:R_0805_2012Metric | 0.18 | FIT | Precision OVP divider bottom.
C101 | 1 | 10n | C0805C103J5GACTU | Capacitor_SMD:C_0805_2012Metric | 0.3 | FIT | Slows Pi/audio startup to about25.5ms nominal; reduces2200uF reservoir charging surge to about0.44A nominal.
C102 | 1 | 4.7n | C0805C472J5GACTU | Capacitor_SMD:C_0805_2012Metric | 0.15 | FIT | 0.426 V/ms nominal slew; about 0.43 A capacitor charging current.
C103 | 1 | 100n | C0805C104K5RACTU | Capacitor_SMD:C_0805_2012Metric | 0.15 | FIT | U2 input bypass.
C104 | 1 | 100n | C0805C104K5RACTU | Capacitor_SMD:C_0805_2012Metric | 0.15 | FIT | U3 input bypass.
C105 | 1 | 2200u 10V | EEU-FR1A222L | Capacitor_THT:CP_Radial_D10.0mm_P5.00mm | 1.3 | FIT | Reverse-isolated Pi/audio reservoir; +/-20%; hand-solder after reflow.
C106 | 1 | 1000u 10V | EEU-FR1A102L | Capacitor_THT:CP_Radial_D8.0mm_P3.50mm | 0.85 | FIT | Servo reservoir; +/-20%; hand-solder after reflow.
C107 | 1 | 10u | C1206C106K4RACTU | Capacitor_SMD:C_1206_3216Metric | 0.15 | FIT | Local decoupling; X7R unless noted.
C108 | 1 | 10u | C1206C106K4RACTU | Capacitor_SMD:C_1206_3216Metric | 0.15 | FIT | Local decoupling; X7R unless noted.
U4 | 1 | TPS389001DSET | TPS389001DSET | Package_SON:WSON-6_1.5x1.5mm_P0.5mm | 2.22 | FIT | 1% supervisor; nominal4.8300V falling and4.8594V rising;107ms nominal qualification and asynchronous arm-latch clear.
R107 | 1 | 32.0k 0.1% | RT0805BRD0732KL | Resistor_SMD:R_0805_2012Metric | 0.1 | FIT | Verified catalog 32k 0.1% supervisor top resistor; nominal fall 4.8300V, rise 4.8594V.
R108 | 1 | 10k 0.1% | RT0805BRD0710KL | Resistor_SMD:R_0805_2012Metric | 0.18 | FIT | UV threshold divider bottom.
R109 | 1 | 2.2k 1% | RC0805FR-072K2L | Resistor_SMD:R_0805_2012Metric | 0.05 | FIT | Supervisor open-drain pullup; 1.5mA sink at3.3V, faster reset-release edge for AUP latch.
C109 | 1 | 100n | C0805C104K5RACTU | Capacitor_SMD:C_0805_2012Metric | 0.15 | FIT | Supervisor supply bypass.
U5 | 1 | SN74LVC1G08DBVR | SN74LVC1G08DBVR | Package_TO_SOT_SMD:SOT-23-5 | 0.35 | FIT | AND of hardware armed latch and software request; request low always disables power.
R110 | 1 | 100k 1% | RC0805FR-07100KL | Resistor_SMD:R_0805_2012Metric | 0.05 | FIT | Keep motor supply off with Pi absent.
R111 | 1 | 100k 1% | RC0805FR-07100KL | Resistor_SMD:R_0805_2012Metric | 0.05 | FIT | Default off during boot.
R112 | 1 | 10k 1% | RC0805FR-0710KL | Resistor_SMD:R_0805_2012Metric | 0.05 | FIT | Fault output pull-up.
R113 | 1 | 10k 1% | RC0805FR-0710KL | Resistor_SMD:R_0805_2012Metric | 0.05 | FIT | Fault output pull-up.
C110 | 1 | 100n | C0805C104K5RACTU | Capacitor_SMD:C_0805_2012Metric | 0.15 | FIT | AND gate bypass.
C111 | 1 | 100n | C0805C104K5RACTU | Capacitor_SMD:C_0805_2012Metric | 0.15 | FIT | Supervisor reset-release delay about107ms nominal; delay qualification only, not fault detection delay.
TP101 | 0 | PI_5V | PCB copper test point | TestPoint:TestPoint_Pad_D1.5mm | 0 | PCB feature | Probe access; no purchased component
TP102 | 0 | SERVO_5V | PCB copper test point | TestPoint:TestPoint_Pad_D1.5mm | 0 | PCB feature | Probe access; no purchased component
TP103 | 0 | SUPPLY_OK | PCB copper test point | TestPoint:TestPoint_Pad_D1.5mm | 0 | PCB feature | Probe access; no purchased component
TP104 | 0 | SERVO_ILM | PCB copper test point | TestPoint:TestPoint_Pad_D1.5mm | 0 | PCB feature | Probe access; no purchased component
TP105 | 0 | PI_FAULT_N | PCB copper test point | TestPoint:TestPoint_Pad_D1.5mm | 0 | PCB feature | Probe access; no purchased component
TP106 | 0 | GND | PCB copper test point | TestPoint:TestPoint_Pad_D1.5mm | 0 | PCB feature | Probe access; no purchased component
J2 | 1 | Pi Zero 2 W carrier socket | SSW-120-01-G-D | Connector_PinSocket_2.54mm:PinSocket_2x20_P2.54mm_Vertical | 4.5 | FIT | Socket on carrier top; male header soldered on Pi underside; all grounds and both 5V pins used.
R201 | 1 | 33 1% | RC0805FR-0733RL | Resistor_SMD:R_0805_2012Metric | 0.05 | FIT | Source damping at Pi, shared clock.
R202 | 1 | 33 1% | RC0805FR-0733RL | Resistor_SMD:R_0805_2012Metric | 0.05 | FIT | Source damping at Pi, shared frame clock.
R203 | 1 | 33 1% | RC0805FR-0733RL | Resistor_SMD:R_0805_2012Metric | 0.05 | FIT | Source damping at Pi.
TP201 | 0 | PI_3V3 | PCB copper test point | TestPoint:TestPoint_Pad_D1.5mm | 0 | PCB feature | Probe access; no purchased component
TP202 | 0 | BCLK | PCB copper test point | TestPoint:TestPoint_Pad_D1.5mm | 0 | PCB feature | Probe access; no purchased component
TP203 | 0 | LRCLK | PCB copper test point | TestPoint:TestPoint_Pad_D1.5mm | 0 | PCB feature | Probe access; no purchased component
TP204 | 0 | MIC_DATA_PI | PCB copper test point | TestPoint:TestPoint_Pad_D1.5mm | 0 | PCB feature | Probe access; no purchased component
TP205 | 0 | GND | PCB copper test point | TestPoint:TestPoint_Pad_D1.5mm | 0 | PCB feature | Probe access; no purchased component
U6 | 1 | ICS-43434 | ICS-43434 | Sensor_Audio:InvenSense_ICS-43434-6_3.5x2.65mm | 4.2 | FIT | Left slot selected. Bottom port through PCB; no paste/flux in port.
R301 | 1 | 47 1% | RC0805FR-0747RL | Resistor_SMD:R_0805_2012Metric | 0.05 | FIT | Quiet local mic supply; 550uA produces only 25.9mV drop.
C301 | 1 | 1u | C0805C105K5RACTU | Capacitor_SMD:C_0805_2012Metric | 0.15 | FIT | Mic RC supply filter.
C302 | 1 | 100n | C0805C104K5RACTU | Capacitor_SMD:C_0805_2012Metric | 0.15 | FIT | Mic immediate bypass.
R302 | 1 | 33 1% | RC0805FR-0733RL | Resistor_SMD:R_0805_2012Metric | 0.05 | FIT | Source termination at microphone.
R303 | 1 | 100k 1% | RC0805FR-07100KL | Resistor_SMD:R_0805_2012Metric | 0.05 | FIT | Defined data level during microphone tri-state slot.
U7 | 1 | MAX98357AETE+T | MAX98357AETE+T | Package_DFN_QFN:TQFN-16-1EP_3x3mm_P0.5mm_EP1.23x1.23mm | 4.08 | FIT | Mono bridge amplifier; A=I2S; EP grounded; both speaker leads driven.
R304 | 0 | 100k 1% | RC0805FR-07100KL | Alfred:R_0805_DNP_NoPaste | 0.05 | DO NOT FIT | DO NOT FIT in revision E: floating GAIN_SLOT selects 9 dB. Optional 100k to VDD selects quiet 3 dB mode.
R305 | 1 | 1k 1% | RC0805FR-071KL | Resistor_SMD:R_0805_2012Metric | 0.05 | FIT | SD_MODE drive isolation; high selects left channel.
R306 | 1 | 100k 1% | RC0805FR-07100KL | Resistor_SMD:R_0805_2012Metric | 0.05 | FIT | Mute through boot; software enables after valid clocks.
C303 | 1 | 100n | C0805C104K5RACTU | Capacitor_SMD:C_0805_2012Metric | 0.15 | FIT | At amplifier supply pins.
C304 | 1 | 10u | C1206C106K4RACTU | Capacitor_SMD:C_1206_3216Metric | 0.15 | FIT | At amplifier supply pins.
C305 | 1 | 100u 10V | EEU-FR1A101 | Capacitor_THT:CP_Radial_D5.0mm_P2.00mm | 0.35 | FIT | Local amplifier bulk.
L1 | 1 | 10uH 3.2A | SRN6045TA-100M | Alfred:SRN6045TA_100M | 0.75 | FIT | Symmetric output LC; 4.6A saturation, DCR 52mOhm maximum; 6x6mm body.
L2 | 1 | 10uH 3.2A | SRN6045TA-100M | Alfred:SRN6045TA_100M | 0.75 | FIT | Symmetric output LC; 4.6A saturation, DCR 52mOhm maximum; 6x6mm body.
C306 | 1 | 220n | C0805C224K5RACTU | Capacitor_SMD:C_0805_2012Metric | 0.15 | FIT | Differential output filter; 20uH total gives 75.9kHz resonance.
C307 | 1 | 1n | C0805C102J5GACTU | Capacitor_SMD:C_0805_2012Metric | 0.15 | FIT | C0G 50V, post-inductor common-mode EMI shunt.
C308 | 1 | 1n | C0805C102J5GACTU | Capacitor_SMD:C_0805_2012Metric | 0.15 | FIT | Matched C0G 50V, post-inductor EMI shunt.
J3 | 1 | Speaker 4ohm 3W | 282834-2 | TerminalBlock_TE-Connectivity:TerminalBlock_TE_282834-2_1x02_P2.54mm_Horizontal | 0.8 | FIT | Screw terminal for bare speaker wires; neither terminal is ground.
TP301 | 0 | MIC_3V3 | PCB copper test point | TestPoint:TestPoint_Pad_D1.5mm | 0 | PCB feature | Probe access; no purchased component
TP302 | 0 | PI_5V | PCB copper test point | TestPoint:TestPoint_Pad_D1.5mm | 0 | PCB feature | Probe access; no purchased component
TP303 | 0 | GND | PCB copper test point | TestPoint:TestPoint_Pad_D1.5mm | 0 | PCB feature | Probe access; no purchased component
U8 | 1 | SN74LVC1G07DBVR | SN74LVC1G07DBVR | Package_TO_SOT_SMD:SOT-23-5 | 0.35 | FIT | 5.5V-tolerant open drain and Ioff isolate Pi from connector +5V faults.
R401 | 1 | 100k 1% | RC0805FR-07100KL | Resistor_SMD:R_0805_2012Metric | 0.05 | FIT | Boot-low PWM.
R402 | 1 | 4.7k 1% | RC0805FR-074K7L | Resistor_SMD:R_0805_2012Metric | 0.05 | FIT | 5V signal pull-up before protective series resistor.
R403 | 1 | 1k 1% | RC0805FR-071KL | Resistor_SMD:R_0805_2012Metric | 0.05 | FIT | A short to +5V sinks at most about 5.3mA; ground short limited by pull-up.
C401 | 1 | 100n | C0805C104K5RACTU | Capacitor_SMD:C_0805_2012Metric | 0.15 | FIT | Buffer bypass.
J4 | 1 | Jaw: GND +5V SIG | TSW-103-07-G-S | Connector_PinHeader_2.54mm:PinHeader_1x03_P2.54mm_Vertical | 0.45 | FIT | Standard servo plug; clearly mark both sides; retention clip recommended.
U9 | 1 | TL431AIDBZR | TL431AIDBZR | Package_TO_SOT_SMD:SOT-23 | 0.4 | FIT | Reference controls regenerative shunt. Verify dynamic stability with actual servo.
R404 | 1 | 12.4k 0.1% | RT0805BRD0712K4L | Resistor_SMD:R_0805_2012Metric | 0.18 | FIT | 2.495*(1+12.4/10)=5.589V nominal dump threshold.
R405 | 1 | 10k 0.1% | RT0805BRD0710KL | Resistor_SMD:R_0805_2012Metric | 0.18 | FIT | Shunt reference bottom.
R406 | 1 | 2.2k 1% | RC0805FR-072K2L | Resistor_SMD:R_0805_2012Metric | 0.05 | FIT | Cathode bias and gate pull-up, ~1.4mA at clamp onset.
R407 | 1 | 100 1% | RC0805FR-07100RL | Resistor_SMD:R_0805_2012Metric | 0.05 | FIT | Isolate capacitive FET gate.
Q3 | 1 | AO3401A | AO3401A | Package_TO_SOT_SMD:SOT-23 | 0.25 | FIT | PMOS shunts excess servo rail energy into R408.
R408 | 1 | 10ohm 5W | SQP500JB-10R | Resistor_THT:R_Axial_Power_L25.0mm_W9.0mm_P30.48mm | 0.6 | FIT | At 5.6V absorbs up to 3.14W. Mount 5mm above PCB, away from plastic.
SW1 | 1 | Momentary button | B3F-1000 | Button_Switch_THT:SW_PUSH_6mm_H4.3mm | 0.3 | FIT | Normally-open, front plunger access. No identity semantics.
R409 | 1 | 1k 1% | RC0805FR-071KL | Resistor_SMD:R_0805_2012Metric | 0.05 | FIT | Limits switch discharge current.
R410 | 1 | 100k 1% | RC0805FR-07100KL | Resistor_SMD:R_0805_2012Metric | 0.05 | FIT | Release RC time constant 10ms.
C402 | 1 | 100n | C0805C104K5RACTU | Capacitor_SMD:C_0805_2012Metric | 0.15 | FIT | Press time constant ~0.1ms; software requires 30ms stable both edges.
U10 | 1 | SN74LVC1G17DBVR | SN74LVC1G17DBVR | Package_TO_SOT_SMD:SOT-23-5 | 0.4 | FIT | Schmitt buffer converts slow RC edges to clean logic.
C403 | 1 | 100n | C0805C104K5RACTU | Capacitor_SMD:C_0805_2012Metric | 0.15 | FIT | Schmitt buffer bypass.
R411 | 1 | 680 1% | RC0805FR-07680RL | Resistor_SMD:R_0805_2012Metric | 0.05 | FIT | About 2mA for green LED Vf~2V.
D3 | 1 | Green status LED | WP710A10SGC | LED_THT:LED_D3.0mm | 0.3 | FIT | Visible via printed light pipe.
TP401 | 0 | JAW_SIG | PCB copper test point | TestPoint:TestPoint_Pad_D1.5mm | 0 | PCB feature | Probe access; no purchased component
TP402 | 0 | SERVO_EN | PCB copper test point | TestPoint:TestPoint_Pad_D1.5mm | 0 | PCB feature | Probe access; no purchased component
TP403 | 0 | BUTTON_N | PCB copper test point | TestPoint:TestPoint_Pad_D1.5mm | 0 | PCB feature | Probe access; no purchased component
TP404 | 0 | GND | PCB copper test point | TestPoint:TestPoint_Pad_D1.5mm | 0 | PCB feature | Probe access; no purchased component
R114 | 1 | 10k 1% | RC0805FR-0710KL | Resistor_SMD:R_0805_2012Metric | 0.05 | FIT | 10k/10k EN divider; 2.55 V nominal at 5.1 V input, with D101 fault clamp.
R115 | 1 | 10k 1% | RC0805FR-0710KL | Resistor_SMD:R_0805_2012Metric | 0.05 | FIT | 10k/10k EN divider; 2.55 V nominal at 5.1 V input, with D101 fault clamp.
D101 | 1 | 5.1V EN clamp | MMSZ5V1T1G | Diode_SMD:D_SOD-123 | 0.17 | FIT | Cathode to EN, anode to ground. Limits EN fault voltage; R114 limits clamp current.
U11 | 1 | 74AUP1G74DC | 74AUP1G74DC,125 | Package_SO:VSSOP-8_2.3x2mm_P0.5mm | 0.46 | FIT | Schmitt-input arm latch; active-low supply-good clears Q asynchronously. New request rising edge required after recovery. Nexperia AUP part, 3.3V only.
C112 | 1 | 100n | C0805C104K5RACTU | Capacitor_SMD:C_0805_2012Metric | 0.15 | FIT | Local bypass for U11 arm latch.

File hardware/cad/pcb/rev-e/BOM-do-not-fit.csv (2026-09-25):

Reference | MPN | Value | Reason
R304 | RC0805FR-07100KL | 100k 1% | DO NOT FIT in revision E: floating GAIN_SLOT selects 9 dB. Optional 100k to VDD selects quiet 3 dB mode.

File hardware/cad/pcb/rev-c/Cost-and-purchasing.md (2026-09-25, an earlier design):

# Price optimization for one Alfred

**The purchase list is leaner, but the improved circuit itself is slightly more expensive.** No order was placed and this is not a complete current-price quotation.

| Comparison | USD allowance |
|---|---:|
| Revision B fitted board components | 40.62 |
| Revision B recommended purchase quantities | 60.80 |
| Revision C lean purchase, fitted board components | 43.06 |
| Reduction versus previous recommended purchase basket | 17.74 |
| External parts, PCB and hardware inherited allowances | 55.35 |
| Revision C combined planning allowance, excluding Pi | 98.41 |

These comparisons use the old component allowances except the newly selected MOSFET ($1.76 each) and clamp diode ($0.17). They mix estimates and two checked indexed price entries; they are not a claim of checkout savings. Shipping, tax, assembly labor, stencil, minimum PCB order quantities and enclosure printing are additional. A fabricator's minimum batch charge can exceed the inherited $20 PCB allowance.

## Changes made
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

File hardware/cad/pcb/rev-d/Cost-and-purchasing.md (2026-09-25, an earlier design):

# Alfred revision D purchasing allowance

Fitted electronics: **$43.71** for one board, **$0.65 above revision C**. Original revision B fitted parts were $40.62; its spare-heavy purchase basket was $60.80. The lean D basket is $17.09 below that old purchasing basket, not cheaper than its fitted circuit.
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

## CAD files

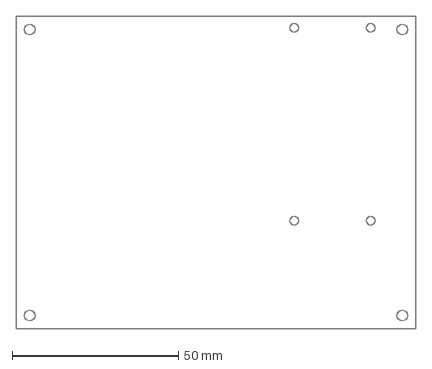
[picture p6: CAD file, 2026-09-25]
hardware/cad/pcb/rev-e/Carrier-outline-holes.dxf
120.0 x 94.0 mm

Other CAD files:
hardware/cad/mechanical/modules-rev-a/Alfred_module_assembly.STEP
hardware/cad/mechanical/rev-b/Alfred_assembly.STEP
hardware/cad/mechanical/modules-rev-a/CAD/04_Speaker_lid.STEP
hardware/cad/mechanical/modules-rev-a/reference-envelopes/power_terminal_and_wires.STEP
hardware/cad/mechanical/modules-rev-a/source/source-cad/01_Plinth.STEP
hardware/cad/mechanical/rev-b/05_Microphone_duct.STEP
hardware/cad/mechanical/modules-rev-a/CAD/16_Button_cap.STEP
hardware/cad/mechanical/modules-rev-a/reference-envelopes/mic_PCB.STEP
hardware/cad/mechanical/modules-rev-a/source/source-cad/07_Button_stem.STEP
hardware/cad/mechanical/rev-b/13_Drive_link.STEP
hardware/cad/pcb/rev-e/Carrier-board-only.step
hardware/cad/mechanical/modules-rev-a/CAD/03_Speaker_mount_modules.STEP
hardware/cad/mechanical/modules-rev-a/reference-envelopes/servo_reservoir_capacitor.STEP
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

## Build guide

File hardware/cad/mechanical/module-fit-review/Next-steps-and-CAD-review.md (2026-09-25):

# Alfred: module prototype and CAD fit review

Status: preliminary dimensional review, not an electronics-inclusive assembly clearance approval. Reviewed 13 September 2026. No native CAD was changed.

## Decision

Keep the Pi Zero 2 W and the existing local Ubuntu server. The Pi runs the microphone, playback, SSH client and jaw timing; the server runs transcription, language generation and synthesized voice. Prototype with assembled audio modules before committing to custom PCB manufacture. Keep one FS90 positional jaw servo, matching the current mechanical assembly; the historical neck-servo idea is not implemented in this CAD.

## Files actually checked

Source: rev-b/

Fresh mesh-audit.json records SHA-256, bounds, watertightness, winding and positive volume for all 16 STL files. All passed those mesh checks. README, generator geometry and existing geometry-audit/jaw-sweep reports were also reviewed. Existing reports show no sampled printed-part collisions from 0 to 20 degrees; that motion test was not rerun here and excluded commercial hardware. Native SolidWorks geometry was not rebuilt in this review.

## Mechanical findings

| Interface | Evidence | Required action |
|---|---|---|
| External size | Plinth mesh 137 x 111.6 mm, top Z=56.8; head reaches Z=202 | Retain external envelope. Overall volume is adequate for a preliminary module layout, not a completed fit approval. |
| Base cavity | Modeled 127 x 101.6 x 50.8 mm above floor | Preserve cosmetic shell; lay out the assembled modules with connector and cable envelopes before changing openings. |
| Bottom cover | Four old PCB support centers (7.5,7.8), (119.5,7.8), (7.5,93.8), (119.5,93.8); support tops Z=9 | Use these supports for a removable adapter tray. Add separate M2.5 Pi mounts and module retention. Account for tray thickness and screw ends. |
| Pi | 65 x 30 mm PCB; old CAD assumes Pi mounted on custom carrier | Existing enclosure supports cannot directly mount the Pi. Establish Pi orientation, header height, SD removal and power-plug access in the new tray. |
| Speaker | Existing nominal pocket 72 wide x 19 deep x 32 high; source now offers Adafruit 3351 at 70 x 17 x 30 in installed orientation | Nominal total slack is 2 mm in each axis, before foam and tolerances. Verify tabs, cable exit and lid. Retain cradle provisionally. Do not infer screw compatibility from envelope fit. |
| Microphone | Duct is tied to old PCB acoustic bore at (13.5,11.8), roof Z=9 | Breakout needs its own support and sealed acoustic adapter. Existing narrow lid is not a breakout mount. Align actual module port, keep it unobstructed and isolate speaker vibration. |
| Button | Stem bottom Z=15.1; old assumed switch actuator top Z=14.9 | Add a supported switch beneath the existing stem or revise stem length. Preserve approximately 0.2 mm initial gap only after checking actual actuator travel and print tolerance. |
| Rear openings | USB X=23.5..43.5, Z=6.5..18.5; SD X=81.5..115.5, Z=19.5..31 | These correspond to the custom PCB arrangement. Recheck/reposition for final Pi and power entry; plug body and removal paths matter, not just connector faces. |
| Servo and jaw | FS90 nominal body 23.2 x 12.5 x 22; cradle is strap-mounted; shaft target Y=58,Z=176, axis X | Actual body, mounting ears, output shaft, horn and cable must be added/measured. Coupon proves body fit only. Verify 8 mm horn radius and 35.114 mm link before powering. |
| Torso/head | Existing geometry and wiring route retained | No module-driven cosmetic redesign indicated. Keep cable service loop behind moving jaw. |

## Prototype hardware baseline

- Raspberry Pi Zero 2 W, microSD and a suitable regulated supply.
- Adafruit ICS-43434 microphone breakout 6049, matching the microphone family already used in the custom design. Exact board/port drawing still needs to be imported before mounting design is released.
- Adafruit MAX98357A amplifier breakout 3006. Listed planar dimensions 19.4 x 17.8 mm. Its published 3 mm height must not be used as the completed assembly envelope: the fitted terminal block, headers and wires require more clearance.
- Adafruit 3351 enclosed 4-ohm, 3 W speaker as the nominal cradle-compatible candidate.
- FS90 positional servo and original horn, existing button function, wiring and mounting hardware.

These are engineering baseline candidates, not a complete purchase list. Header soldering may still be required. No purchase has been made. The module mic/amp still require Pi audio configuration and real target testing; the previous custom-board overlay is not automatically validated by choosing similar chips.

## Next steps in order

1. Finish the prototype wiring/power design and complete module/connector list. Allocate audio pins and a servo timing method that does not conflict with I2S. Preserve controlled servo startup. Size and separate the motor power branch; do not power the servo from a GPIO or route its current through the Pi. For early bench tests, separate regulated motor power with common ground is practical; it is not a change to the final one-cable requirement. Avoid tying two supply outputs together.
2. Add exact purchased-part envelopes to the CAD assembly, including terminal blocks, headers, horn, plugs and cable bends. Design the adapter tray, microphone support/duct interface and switch support; then update rear access only where necessary. Run static and motion clearances including those parts. Do not print the existing base as a final module-compatible enclosure yet.
3. Obtain the prototype electronics after the list is complete. Print fit coupon 15 first, then servo cradle 12, drive link 13 and jaw 10 as test pieces. Measure the real servo shaft and horn against the CAD target before committing to cosmetic prints.
4. Prove the Pi client on the bench: record speech, send it to the existing local server, play streamed replies and reconnect after a network interruption. Confirm audio levels and buffering. Then add synchronized servo motion, starting with the horn/link disconnected and a small calibrated travel range.
5. Test the installed electronics: speaker loudness, microphone pickup, servo interference, supply droop and Pi undervoltage reporting, temperatures, startup/restart behavior and cable clearance. Run an extended conversation session at the intended loudness and motion settings. Log outcomes rather than treating CAD or electrical-rule checks as physical validation.
6. Incorporate measured fit corrections, print the final base internals and cosmetic pieces, and assemble. Decide afterward whether a custom PCB provides enough benefit to justify fabrication; the earlier PCB Rev E remains incomplete and is not an ordering release.

## Manufacturer references

- Pi: https://www.raspberrypi.com/products/raspberry-pi-zero-2-w/
- Microphone: https://www.adafruit.com/product/6049
- Amplifier: https://www.adafruit.com/product/3006
- Speaker dimensions: https://www.adafruit.com/product/3351
- Servo: https://www.pololu.com/product/2818/specs

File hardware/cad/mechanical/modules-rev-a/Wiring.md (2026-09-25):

# Alfred module prototype — wiring

Use the Pi's **physical header pin numbers** in this table; BCM numbers identify signals in software. Wire with power removed. The server connection is Wi-Fi plus the project's existing SSH tunnel.

| Pi physical pin | BCM / function | Connection |
|---:|---|---|
| 1 | 3.3 V | Mic 3V/VDD; PCA9685 VCC; OE pull-up and button pull-up |
| 2 and 4 | 5 V input | Same fused Pi/audio +5 V branch, split to both contacts |
| 6 and 9 | Ground | Star ground, split to both contacts; all module grounds common |
| 3 | GPIO2 / SDA | PCA9685 SDA |
| 5 | GPIO3 / SCL | PCA9685 SCL |
| 12 | GPIO18 / PCM clock | Mic BCLK and amplifier BCLK |
| 35 | GPIO19 / PCM frame | Mic LRCL/WS and amplifier LRC |
| 38 | GPIO20 / PCM input | Mic DOUT |
| 40 | GPIO21 / PCM output | Amplifier DIN |
| 11 | GPIO17 | Amplifier SD, controlled by the included audio overlay |
| 15 | GPIO22 | PCA9685 OE, active HIGH disables servo pulses |
| 13 | GPIO27 | Identity button input; normally open switch to ground |

Additional connections:

- Mic SEL to GND for the left channel. The mic is a 3.3 V part; never connect its supply or logic to 5 V.
- Amplifier VIN to fused Pi/audio +5 V directly from distribution, not through the Pi header's output path. GND to star ground. Leave GAIN unconnected for the module default; start at low digital volume. Add 10 kohm from SD to GND so it starts disabled despite the module's weak pull-up.
- Speaker's two leads go only to the amplifier's two speaker terminals. Neither speaker terminal goes to ground; the amplifier output is bridged.
- PCA9685 VCC is 3.3 V logic; V+ is the separately fused 5 V motor branch. They are different nets. Use channel 0 for the servo: signal to yellow/orange, V+ to red, GND to brown/black, after checking the actual servo's labeling.
- Add **1 kohm from OE to 3.3 V**, retaining the board's existing 10 kohm pull-down. This holds OE near 3 V while GPIO22 is an input; driving GPIO22 LOW enables pulses. GPIO22 HIGH disables them. At LOW the pull-up draws about 3.3 mA. This is the opposite polarity/function of GPIO22 on the old custom PCB.
- Fit a 10 kohm pull-up from GPIO27 to 3.3 V. Wire the opposite switch contact to GND; check the internally paired legs of the four-leg tactile switch with a meter. Software debounce around 30 ms is a starting point.
- Fit 470–1000 uF / 10 V at PCA9685 V+ to GND with correct polarity and short leads, within the reserved diameter 8 x height 20 mm envelope. This reduces some transients; it is not a substitute for measurement.
- Keep I2S wires short, preferably below 100 mm, paired with nearby ground returns. Separate the motor/speaker wiring from microphone and I2S wiring.

## One-cable power

```text
Official Pi USB-C supply
  -> HUSB238 board, fixed 5 V / 3 A request
       + -> F1 2.5 A -> Pi 5 V inputs + amplifier VIN
       + -> F2 1.25 A -> removable MOTOR power link -> PCA9685 V+
       - -> star ground -> Pi, microphone, amplifier, PCA9685 and servo
```

On Adafruit 5807, **leave the 5V jumper closed**. Cut the factory 1A jumper and leave the 2A jumper open to request 3 A. Leave every higher-voltage jumper open. Do not connect the HUSB238 I2C pins to the Pi; fixed jumpers avoid software changing its output voltage. Inspect jumper continuity and measure unloaded output before connecting anything. Leaving all voltage jumpers open can request a damaging higher voltage.

Use 22 AWG stranded wire for power and ground branches with insulated soldered joints or properly rated connectors. A hand-wired isolated-pad perfboard or insulated harness can hold the two axial fuses; do not rely on thin perfboard copper tracks to carry combined load. Put fuses near the split and mechanically support the leads. A removable 2.54 mm power shunt rated at least 2 A provides the MOTOR link for bench isolation; mark its position clearly.

This arrangement powers the Pi through the header. **Do not simultaneously connect a powered cable to either Pi micro-USB socket.** Use network access for configuration. Any later USB peripheral/debug connection needs a deliberate backfeed-safe power arrangement.

Initial operating budget: Pi 0.75 A + amplifier 0.85 A + servo 0.80 A + other 0.05 A = 2.45 A. These are engineering allocations, not measured limits. No external USB loads are included. The 3 A request leaves 0.55 A nominal margin. A supply contract is not an active branch current limiter, and the fuses do not hold current to their nameplate values.

At 1.6 A the 2.5 A fuse's nominal cold resistance of 0.036 ohm contributes about 58 mV drop. At 0.8 A the 1.25 A motor fuse's 0.10 ohm contributes about 80 mV. Add wiring, PD-board MOSFET, connector and hot-fuse losses; these figures are not a worst-case power guarantee. Require measured stable voltage at the Pi and servo during the combined load test. Do not accept repeated Pi undervoltage events or servo-induced resets.

## Startup and shutdown

For first bring-up, keep the MOTOR link removed and the mechanical link detached. Set OE HIGH, initialize PCA9685 at 50 Hz and set channel 0 to a calibrated safe pulse before enabling OE. Keep all unused channels disabled. Establish the correct pulse direction and closed position before engaging the jaw mechanism.

The application must disable OE on errors and normal exit. On a program hang the PCA9685 can keep its last pulse running; there is no independent watchdog in this prototype. Do not present this as the old PCB's hardware fault latch. If the motor jams, remove motor power; a fuse may not open at stall current.

Never copy the old PCB's GPIO22 HIGH-to-arm code into this build: **HIGH means servo outputs OFF here**. GPIO25 supply-good and the old fault inputs do not exist. GPIO12 PWM overlay is unnecessary because the PCA9685 owns servo timing.

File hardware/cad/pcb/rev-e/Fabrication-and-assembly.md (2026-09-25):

# Alfred revision E fabrication and assembly

This is an unbuilt first article. The routed PCB is a native KiCad 10 board, validated with KiCad 10.0.6. The original unrouted revisions A and B remain separate.

## Fabrication specification

- Outline: 120.0 x 94.0 mm, nominal 1.6 mm FR-4, four copper layers. Copper order is F.Cu / In1.Cu / In2.Cu / B.Cu.
- Specify **35 um finished copper on all four layers**. Do not silently accept 17 um inner copper: the power distribution is on In2.Cu. Request a symmetrical standard stack with approximately 0.2 mm outer-to-inner dielectric and the balance in the core; exact impedance is not controlled.
- L1: components, signals, local power spreading. L2: ground reference. L3: separate protected power regions. L4: signals and input switch copper.
- Minimum trace and copper clearance: 0.15 mm. Ordinary signals are 0.20 mm. Via pad/drill: 0.60/0.30 mm; minimum drill-to-drill edge clearance 0.25 mm. Copper-to-edge minimum 0.30 mm. The USB manufacturer's NPTH-to-copper geometry uses the project minimum hole clearance of 0.15 mm.
- ENIG finish preferred for QFN and microphone assembly; lead-free HASL is less flat. Green solder mask, white top silkscreen. No bottom components.
- All eight mounting holes and the 0.50 mm microphone acoustic bore are NPTH. USB shield slots are plated; use the Excellon routed-slot data. Preserve drill files separately for plated and non-plated features.
- Ordinary vias are tented on both sides. U1 and U7 each have a 0.30 mm thermal via in the exposed ground pad. The top pad aperture remains exposed; bottom tenting is requested. Via filling/capping is not specified. Inspect for solder loss into these holes during first-article reflow.
- Use a 0.10 mm stencil for the QFN, MEMS mic and tiny eFuse lands. Inspect the stencil apertures against the supplied F.Paste Gerber, including U2/U3's joined corner-pad shapes. No paste belongs in the mic bore. Apply a conservative paste volume to the thermal pads; do not hand-flood them.
- The Gerber ZIP contains only production layers and drill data. Assembly drawings and coordinate tables are separate.

## Routing decisions

High-current eFuse inputs and outputs expand into top copper and six-via banks. Their 0.30 mm necks are short escapes from 0.30 mm package lands, not long power traces. Broad internal copper carries the Pi and servo current. Each MOSFET current pin has a separate 0.60 mm escape and via. USB power contacts use multiple vias and bottom copper. Power and ground pads connect directly to planes; expect to need an adequately powered soldering iron for the through-hole connectors and bulk capacitors.

Speaker paths are widened where pad and trace spacing permits, with short finer branches at the IC and filter capacitors. The switching outputs terminate in the two 10 uH inductors; the differential capacitor is on their speaker side. Keep the external speaker wires together and short. Neither speaker terminal is ground.

The second layer is the common ground reference. Mic, logic and protection ground lands have local vias; the servo return enters near its bulk capacitor. Power does not traverse the microphone region. The antenna rectangle and mounting-hardware clearances have actual copper keepouts, not just drawing notes. Use nylon Pi mounting hardware, especially at H8 in the antenna region.

## Revision E population

R107 is 32.0k 0.1%, RT0805BRD0732KL. R101 is 1.65k 0.1%, RT0805BRD071K65L. C101 is 10nF C0G 5%, C0805C103J5GACTU. All three use their existing 0805 footprints. The PCB connectivity and component positions are unchanged from revision D.

U4 remains TPS389001DSET, U11 remains Nexperia 74AUP1G74DC,125, and Q1/Q2 remain SI4459BDY-T1-GE3. Do not substitute generic logic families. R304 remains DO NOT FIT with no stencil apertures. Use the updated BOM and the power acceptance limits.

## Assembly order

1. Reflow SMT parts, with the mic and QFNs carefully aligned. Follow the microphone manufacturer's moisture/reflow handling instructions. Do not ultrasonically clean or force liquid/air into the mic port.
2. Inspect the QFN and RPW land joints under magnification. Check rail-to-ground resistance and input-switch orientation before applying power.
3. Hand-solder the electrolytics, connectors, socket, button and LED. Observe capacitor polarity. Mount R408 6 mm above the board and keep plastic/wires at least 5 mm from its body.
4. Trim underside leads within the mechanical allowance. Use the specified removable Pi header arrangement and supports; do not force a misaligned 40-pin socket.
5. Fit the mic gasket and separate acoustic duct. Keep speaker and servo vibration away from it. Check the SD service window against the actual mated Pi.

## First-article acceptance tests

These are physical tests still to perform; CAD checks do not establish them.

- With Pi/servo disconnected, use a current-limited bench setup or monitored specified PD source. Verify requested 5 V contract, polarity, PI_5V, and that the servo rail is initially off. Do not bypass the PD power path in normal service.
- Use the specified Raspberry Pi 27 W USB-C supply with its captive cable, supporting 5.1 V / 5 A. A generic 'USB-C charger' is not an equivalent substitute.
- Confirm no two supplies drive the Pi 5 V rail simultaneously. Do not power the Pi through its own power connector while this carrier supplies the header.
- Exercise the servo supply first with an electronic load. Check current limit, latch-off/recovery behavior and SUPPLY_OK shutdown threshold. Scope PI_5V at the Pi header with a short ground spring.
- With Pi and audio active, command rapid jaw movement and brief controlled load transients. Avoid sustained mechanical stall. Check the Pi undervoltage status and verify the minimum rail voltage during the transient. Verify the 5.59 V nominal regeneration clamp under an injected regenerative pulse and check R408 temperature.
- Check sustained maximum intended speaker volume for clipping, excessive IC/inductor temperature and audible artifacts. Confirm the filter response with the actual speaker.
- Prove simultaneous capture/playback at one common I2S sample format and rate on the chosen Linux image before relying on barge-in. Echo cancellation is a separate system requirement; shared clocks alone do not provide it.
- Confirm button debounce and servo enable/PWM startup behavior. Calibrate jaw endpoints so the linkage cannot force the servo against a stop.

No physical board has been manufactured or tested, and no purchasing cart has been ordered. See Cost-and-purchasing.md for the revised mixed estimate and checked-price basis; prices and availability require a current supplier quote.

The board outline is defined by the Edge.Cuts centerline: exactly 120 x 94 mm. The Gerber job size uses that centerline, excluding the outline stroke width.

Gerber job Size is normalized to the 120 x 94 mm outline centerline. KiCad export includes the 0.1 mm outline stroke; normalize Size after re-export.

Revision E fault test: hold GPIO22 HIGH, induce a detected undervoltage event, restore the rail, and confirm servo power stays OFF. After supply-good is stable, bring GPIO22 LOW for at least 10 ms, then HIGH to re-arm. Test with a current-limited load before fitting the linkage.

Revision E: Pi/audio startup is now about25.5ms nominal; servo startup remains about12ms. Follow Power-acceptance.md before claiming combined-load operation.

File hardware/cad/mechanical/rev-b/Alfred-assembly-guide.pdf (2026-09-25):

# A1-4RD / Alfred - Assembly guide

Revision B | 202 mm / 7.95 inch bust | Bambu P1 | dimensions in mm

Native SolidWorks prototype with 15 installed printed components and one fit coupon. Bronze denotes visible PLA parts; blue denotes internal PETG parts. Numbers match filenames. Exploded offsets are illustrative, not installation dimensions.


Body revision: broad upper shoulders, tapered tuxedo chest and integral oval socle. Hair, moustache and ears are integral head details. Head structure: connected 4 mm side rails, upper and lower crossmembers, reinforced axle bearings and a thicker rear neck root. The face includes solid eyes, pupils, lids and brows. Purchased electronics and fasteners are omitted from this mechanical schematic.

# Parts and print preparation

No. | Part | Material
01 | Plinth | Bronze PLA
02 | Bottom cover | PETG
03 | Speaker mount | PETG
04 | Speaker lid | PETG
05 | Microphone duct | PETG
06 | Microphone duct lid | PETG
07 | Button stem | PETG
08 | Torso | Bronze PLA
09 | Alfred head | Bronze PLA
10 | Moving jaw | Bronze PLA
11 | Name plaque | Bronze PLA
12 | Servo cradle | PETG
13 | Drive link | PETG
14 | Rear cover | Bronze PLA
15 | Fit coupon | PETG
16 | Button cap | Bronze PLA
1. Print the fit coupon (15) first. Check the actual servo body and axle fit. Then print the jaw, cradle and link before committing to the cosmetic pieces. Commercial servo shaft position is provisional; verify against the next page.
2. Slice each STL as a separate object. Files retain assembly coordinates. Use Lay on Face and Drop to Bed. Start with 0.4 mm nozzle, 0.12-0.16 mm face layers, 0.20 mm general layers. Use six walls on the head, four to five on mechanical supports, and solid infill on the link. Print the 0.5 mm mic lid at 0.1 mm layers.
3. Prepare hardware. A smooth 3 mm axle, approximately 50 mm before trimming; M2 pivot screws, spacers and locknuts; narrow servo ties; M3 PCB, bottom and torso screws. Nominal screw lengths and pilot sizes are in README. Ream axle bores for free rotation. Select screw lengths by actual stack thickness.

# Mechanical schematic - right-side view


Closed-jaw reference shown. X is perpendicular to this page. Jaw axle: Y=52, Z=143. Servo shaft target: Y=58, Z=176, axis parallel to X. Link occupies X=79.5 to 81.9. Supplied servo spline and horn are required; set horn hole radius to 8 mm.

4. Fit the servo before final assembly. Strap the FS90 positional servo into cradle (12). Check its shaft against the reference above. Adjust cradle or linkage if needed; the commercial servo is not modeled. Attach cradle with its M2 base screw and keep wires away from the link.
5. Assemble the jaw on the bench. Place jaw (10) between the reinforced head bearings. Pass the smooth axle through head and jaw, trim and retain both ends. Connect link (13) to the jaw rear pin and horn with M2 screws, spacers and locknuts. Pivots must remain loose enough to rotate.
6. Calibrate before attaching the powered horn. Center the servo electrically, disconnect power, then install the horn at the closed reference. Move the mechanism gently by hand through its intended range before powering it. Start with a small command range, expanding only to a free 0-20 degree jaw opening.

Jaw / geometric crank angle: 0 / 180.000; 5 / 173.513; 10 / 166.483; 15 / 158.776; 20 / 150.181 degrees. These are geometry angles, not PWM values. Firmware must be calibrated to the actual servo.

# Assembly order and final checks

7. Build the bottom module. Bond mic duct (05) to bottom cover (02) at its modeled position. Clean and close it with lid (06). Seal the lid bore to the PCB underside microphone port with a thin gasket. Keep adhesive out of the acoustic channel. Fit the carrier PCB on its four supports, then the Pi using its PCB mounting hardware.
8. Install the speaker. Pad mount (03) for the nominal 70 x 31 x 17 enclosed speaker. Bond the mount to the inner front wall of plinth (01), at the supplied model position, without loading the PCB. Add lid (04), retained with removable tape or a light strap. Keep the factory speaker enclosure intact.
9. Fit the button. Insert stem (07) from below the plinth guide. Bond cap (16) onto the stem from above, keeping glue out of the guide. Check the switch before bonding: this prototype assumes its actuator is 4.3 mm above PCB top, with 0.2 mm resting clearance.
10. Attach torso and route wiring. Fasten torso (08) from inside the plinth with two M3 screws. Pass the servo cable through the torso and neck. Leave a service loop. Fit head (09) into the torso socket; lightly bond only after alignment and mechanism checks. Leave rear access open.
11. Connect and close. Connect speaker, mic, button and servo according to the carrier PCB electrical documentation. This guide is mechanical and does not substitute for that circuit schematic. Secure cables clear of the jaw and Pi antenna. Fit the bottom module and check rear USB/SD access before fastening its four screws.
12. Finish the bust. Bond A1-4RD plaque (11) to the front recess. Fit rear cover (14), using narrow removable tape around the seam for this prototype. Check that removal still gives servo access.
13. Test assembled behavior. Check button return, clear sound, microphone pickup and free jaw travel. Run the actual electronics and check internal temperature before extended use. Revisit support fit and fastener tension after the first operating session.

# Validation and limits

All 16 parts passed SolidWorks solid-body checks. Static checks found no interference among the 15 printed assembly components. Jaw/link samples at every 1 degree from 0 to 20 showed no intersection with the modeled head, torso, servo cradle or rear cover. These are sampled geometry checks, not a physical load, continuous-motion or purchased-component clearance certification. See included JSON reports.

This is an unbuilt prototype. Confirm actual servo shaft position, header stack, speaker envelope and switch travel before the full print. The assembly is a fixed positional reference, not a mated motion simulation. The head clearance feature must be recalculated after relevant geometry changes; see README.

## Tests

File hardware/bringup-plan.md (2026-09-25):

# Alfred physical build: first prototype

The repository has a working Windows laptop client and Linux server. No body,
carrier PCB, Pi client, jaw mechanism, or neck mechanism has been built or
purchased yet. Anton now uses an MI50 for Alfred's model. This plan starts with
a bench prototype so the PCB and enclosure can be based on measured interfaces.

On 2026-09-23, Anton reported `gemma4:26b-a4b-it-q8_0` in `ollama ps`; the user
described the current model as “gemma4 28b.” Confirm the intended model tag
separately if server documentation is updated. The model choice does not change
the physical client's requirements.

## Fixed project choices

- Six-inch printed figure, moving jaw, nodding neck.
- Raspberry Pi Zero 2 W in the base; server keeps Whisper, model, memory, and TTS.
- One USB-C power input; I2S microphone and mono class-D speaker amplifier.
- Two small 5 V servos, one button, one visible status indicator.
- V2 base adds an approximately four-inch screen for Alfred's words; see
  [display-v2.md](display-v2.md) for the preliminary interface.

## Build order and pass criteria

1. **Bring up a Pi Zero 2 W on the bench.** Boot Raspberry Pi OS, connect to
   Wi-Fi, SSH into Anton, and verify the existing server endpoints through the
   tunnel. Use a suitable micro-USB supply for the Pi during this stage.
2. **Run the existing client on the Pi with temporary audio devices.** Verify
   Wi-Fi/SSH tunnel, microphone capture, sentence playback, and music playback.
   `client/listen.py`, `client/talk.py`, and `client/music.py` already have the
   server protocol, but contain Windows/WASAPI assumptions. The Pi port is work
   to do; the existing laptop client is not proof that the Pi client runs.
3. **Prove the chosen I2S microphone and amplifier together.** Wire both to a
   Zero 2 W on a bench, with shared BCLK and LRCLK and separate DIN/DOUT. Use a
   single sound-card configuration that exposes capture and playback. Record and
   play at the same time for at least ten minutes; check captured samples,
   playback dropouts, and `dmesg`. Test cold boots too. Separate stock overlays
   can each work alone yet fail when both claim the same I2S controller. Do not
   lock in either chip or the PCB until this passes.
4. **Measure power at the actual loads.** With a current-limited bench supply,
   record Pi boot/Wi-Fi peaks, amplifier draw at the intended maximum volume,
   each servo's movement and stall current, and the worst simultaneous event.
   Measure the voltage at the Pi 5 V header during both servos starting and
   reversing. Set the supply, connector, switch, traces, and protection from
   those measurements; the Pi's 2 A recommended supply is for the Pi, not this
   complete assembly.
5. **Measure the mechanical envelope and prototype the mechanisms.** Record
   available base diameter/width, depth, internal height, head volume, jaw
   pivot, neck axis, and intended print material. Use the official Pi Zero 2 W
   mechanical drawing for Pi and connector keep-outs. Print the head/jaw pivot
   and neck joint with
   temporary servo mounts. Measure jaw closed/open angles, usable servo pulse
   range, linkage travel, physical stops, and clearance. Verify smooth motion
   without servo buzzing or binding before designing the final enclosure.
6. **Freeze interfaces, then design the carrier.** Capture board outline,
   mounting-hole coordinates, Pi orientation and SD access, USB-C edge,
   microphone port alignment, speaker chamber, servo connectors, wire path,
   and V2 display power and mini-HDMI cable clearance.
   Only then prepare schematic, BOM, and board layout.

## First bench parts

Buy only enough to test the interfaces before committing to the enclosure or
custom PCB:

| Part | Quantity | Why now |
| --- | ---: | --- |
| Raspberry Pi Zero 2 W with soldered 40-pin header | 1 | Client target and GPIO access |
| microSD card, micro-USB Pi supply, female jumper wires, breadboard | 1 each | Boot and temporary wiring |
| I2S MEMS microphone breakout, e.g. SPH0645LM4H | 1 | Prove Pi capture and the eventual mic path |
| MAX98357A I2S mono amplifier breakout | 1 | Prove Pi playback on the same I2S controller |
| 4–8 Ω speaker rated for the amplifier's intended output | 1 | Audio test; final diameter waits for enclosure measurements |

The listed mic and amp are *candidates for a bench test*, not yet approved for
the carrier. The mic driver and the combined Linux sound-card configuration need
the simultaneous test above. Wait to choose the two servo models and USB-C
power components until the head geometry and load measurements are available.

## Electrical architecture to prove

```
USB-C 5 V sink -> attach/inrush and fault protection -> 5 V distribution
                                                 |-> Pi Zero 2 W
                                                 |-> audio amplifier
                                                 `-> switched/current-limited servo branch
Pi 3.3 V -> I2S microphone, button input, status LED circuit
Pi GPIO -> servo-control signals (through suitable protection)
```

Keep the servo branch's high-current path away from the Pi feed and microphone.
All branches still share a ground reference. A separate servo regulator is not
automatically a fix when its input is the same 5 V source: the supply and cable
must support total load, and the Pi must stay above its operating threshold at
its own pins during transients. Decide bulk capacitance and branch protection
from the scope/current measurements, not a generic capacitor value.

For a 5 V sink-only USB-C receptacle, CC1 and CC2 each need their own 5.1 kΩ
pull-down to ground. A design with substantial downstream bulk capacitance needs
an attach-controlled power path so that capacitance is not exposed directly on
VBUS at plug-in. A plain 5 V Type-C source can advertise at most 3 A; verify its
advertisement and the cable before treating 3 A as available. If measured load
exceeds that, revisit the power architecture before making the PCB.

## Security boundary for the button

The button can request a profile or start an identification step. It cannot
authenticate a person by itself. Until an identity check exists, any press-based
profile should be treated as unverified and should not unlock private memory.
The server's memory lookup must enforce that boundary.

## Measurements needed to finish CAD and PCB

| Item | Record |
| --- | --- |
| Base and head | Outer and usable internal dimensions, wall thickness, print material |
| Pi | Header orientation, SD and port access, mounting/stack height |
| Jaw | Pivot coordinates, closed/open angles, linkage space, physical stops |
| Neck | Pivot axis, target nod angle, wire passage, stop positions |
| Servos | Exact model, body/horn dimensions, motion/stall current at 5 V |
| Audio | Exact mic, amp and speaker; speaker diameter/depth/impedance and port positions |
| Power | Pi/amp/servo current traces and lowest Pi voltage during simultaneous motion |
| Assembly | Fasteners, service opening, connector access, cable strain relief |

## Source notes

- [Raspberry Pi Zero 2 W official drawings and schematics](https://pip.raspberrypi.com/categories/584)
- [Raspberry Pi power recommendations](https://www.raspberrypi.com/documentation/computers/raspberry-pi.html)
- [Adafruit SPH0645LM4H I2S microphone breakout](https://www.adafruit.com/product/3421)
- [Adafruit MAX98357A I2S amplifier breakout](https://www.adafruit.com/product/3006)
- [Raspberry Pi device tree overlay reference](https://github.com/raspberrypi/firmware/blob/master/boot/overlays/README)
- [Reported failure when separate I2S mic and amp overlays both claim the Pi controller](https://forums.raspberrypi.com/viewtopic.php?t=317483)
- [TI USB-C sink design guide, pages 53–54](https://www.ti.com/lit/pdf/slyy228)

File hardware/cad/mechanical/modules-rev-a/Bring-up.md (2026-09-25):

# Bench qualification before final printing

No physical test has been performed yet. Record observations, actual part revisions and loaded voltages as the build progresses.

1. **Mechanical coupon:** test the actual servo and the 3 mm axle fit. The existing cradle/shaft/horn geometry remains provisional. Do not commit to the full head print until this is resolved.
2. **Power only:** with everything disconnected, configure the HUSB238 for 5 V / 3 A. Inspect jumpers and polarity; confirm output remains in the intended 5 V range. Test with a suitable dummy load before adding the Pi. Never use a higher PD voltage directly.
3. **Pi alone:** install Raspberry Pi OS Lite, reconnect the existing client to the local server via its established SSH configuration, and confirm restart/reconnect behavior. Keep private keys and server credentials out of this hardware package.
4. **Audio:** follow software/README.md. Confirm both streams enumerate; record clear speech, play a quiet test tone, then run actual server replies. Verify channel selection, sample conversion and streaming buffer behavior. Do not run the smoke test concurrently with the Alfred client.
5. **Servo separately:** MOTOR link removed and mechanism detached. Verify OE starts HIGH; initialize pulses, then enable motor power deliberately. Establish conservative physical limits around the actual installed horn. A nominal 1500 us pulse is only a centering starting point, not Alfred's guaranteed closed position.
6. **Jaw:** verify shaft placement, 8 mm horn radius and 35.114 mm link. Move by hand with power disconnected before testing a small powered range. Increase only within free motion; target jaw travel remains 0–20 degrees. Confirm the cable and rear cover remain clear throughout motion.
7. **Combined load:** play the intended loudest speech while cycling the jaw. Measure voltage at the Pi and servo, preferably with an oscilloscope to catch fast dips/spikes. Target Pi rail at least 4.85 V during this test, within its permitted maximum; investigate any undervoltage flags or resets. Check servo supply against the actual FS90's 4.8–6 V rating. Test startup with the reservoir capacitor fitted; repeated fuse opening means investigate inrush or faults, not simply increase fuse size.
8. **Enclosed run:** secure the harness and repeat a 30-minute conversation/motion session with the base closed. Check temperatures, noise pickup, Wi-Fi reliability, microphone response and jaw looseness afterward. Verify restart and application-error behavior. This test is supervised because the module prototype does not provide independent fault power cutoff.

Proceed to final cosmetic printing and normal assembly only after the physical fit, power and audio tests pass. Purchasing can then use the selected module list with any measured changes incorporated.

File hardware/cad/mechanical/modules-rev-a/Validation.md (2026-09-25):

# Validation record

This record applies to the module prototype files in this directory, not the earlier custom PCB releases.

- All 18 printable STL files reopened with trimesh: watertight, consistent winding, positive volume.
- Exact BRep intersection tests found no volumetric intersections between the printed assembly and the included board/component/service envelopes, or between different module groups. Refer to clearance-check.json for the actual report.
- The same checks include the four base tray screw-head envelopes, the microphone solder-tail clearance, the servo-board reservoir capacitor and the USB-C plug envelope. Touching assembly interfaces (e.g. board seats and speaker floor) are intentional.
- New/revised STEP solids and the assembly were independently reimported. STEP-reimport-check.json records kernel validity and solid counts.
- The CAD runtime exits with code 1 without a Python traceback, even for a minimal import-and-version-print command. Export completion alone was therefore not treated as success: files were reopened and explicit geometry checks written separately. The runtime exit issue remains an environment limitation.
- Mesh checks do not establish print tolerances or strength. Board planar outlines/mounting holes come from manufacturer source files; tall components and connectors are simplified clearance envelopes, not certified supplier models. M2 fastener dimensions must be checked against the selected screws and washers; not all fasteners are individually modeled.
- The actual servo and horn are not modeled. The original cradle dimensions require a real fit check and possibly a revision; this package does not approve it. Previously supplied 0–20 degree jaw-motion results only concerned printed components.
- No physical power, thermal, audio, Wi-Fi, Pi boot, OS-driver or servo calibration tests were performed. The included overlay remains uncompiled on this Windows host.
- No purchasing or manufacturing action was performed. Basic module fuses/OE do not replicate the custom PCB's active fault protection.

Use the fit coupon and supervised bench sequence before final cosmetic printing.

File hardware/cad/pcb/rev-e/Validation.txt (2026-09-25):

Alfred revision D - 2026-09-12 - KiCad 10.0.6
DRC: 0 violations, 0 unconnected items, 0 schematic parity issues.
ERC: 0 errors, 0 warnings.
All-track errors and all DRC severities (including exclusions) requested.
Inherited ignored categories remain recorded in the reports; no new exclusions added.
Fresh schematic netlist to PCB pad entries: 368; 0 mismatches.
BOM values, MPNs, footprint IDs and DNP status: match PCB.
R304: DNP and no F.Paste layer on either pad.
Connectors and mounting holes: positions and rotations match revision C.
Stackup: four layers, 35 um copper each; outline centerline 120 x 94 mm.
Manufacturing files: all 9 Gerber layers and both drill files freshly exported.
Logic model: all 65,536 eight-event command/fault sequences pass.
PDFs: all 11 pages rendered and visually inspected; changed latch detail inspected.
Audio tone: stereo S32_LE 48 kHz, duration and -30 dBFS amplitude checked.
Grouped fitted BOM allowance: $43.71; not a supplier quotation.

No analog simulation, physical board test, target overlay compile or acoustic test.
Static and transient operating limits and required tests: Design-notes.md.

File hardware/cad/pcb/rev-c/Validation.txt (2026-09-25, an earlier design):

Alfred rev C - 2026-09-10, KiCad 10.0.6
DRC violations: 0
Unconnected items: 0
Schematic parity issues: 0
ERC errors: 0
ERC warnings: 0
Fresh schematic/PCB pad-net entries compared: 358; mismatches 0
Values and DNP status checked against design-data.json: all match
Electrical footprints: 115 (includes test points and DNP R304)
Board outline and fixed connector coordinates unchanged from revision B.
No new DRC exclusions or disabled checks were added.
Existing ignored categories are enumerated in DRC-report.json and ERC-report.txt.

This validates CAD consistency and checked clearances. It does NOT establish physical
PD startup, gate timing, brownout immunity, thermal margins, audio software behavior,
EMC, microphone acoustics or enclosure fit. This is an unbuilt first article.
Audio overlay source reviewed; target compile and physical tests remain necessary.

Final package QA: all 11 PDF pages rendered and visually inspected.
Assembly plot omits duplicate fabrication reference text in a plotting-only copy.
Audio test tone format, duration, stereo duplication and -30 dBFS level checked.
Target overlay compilation and physical audio tests remain outstanding.

2026-09-11 independent self-review: fresh DRC/ERC and 358 pad comparisons pass.
Nine Gerber layers match fresh exports excluding creation timestamps.
See Self-review.md for unresolved servo power margin and hardware retry behavior.

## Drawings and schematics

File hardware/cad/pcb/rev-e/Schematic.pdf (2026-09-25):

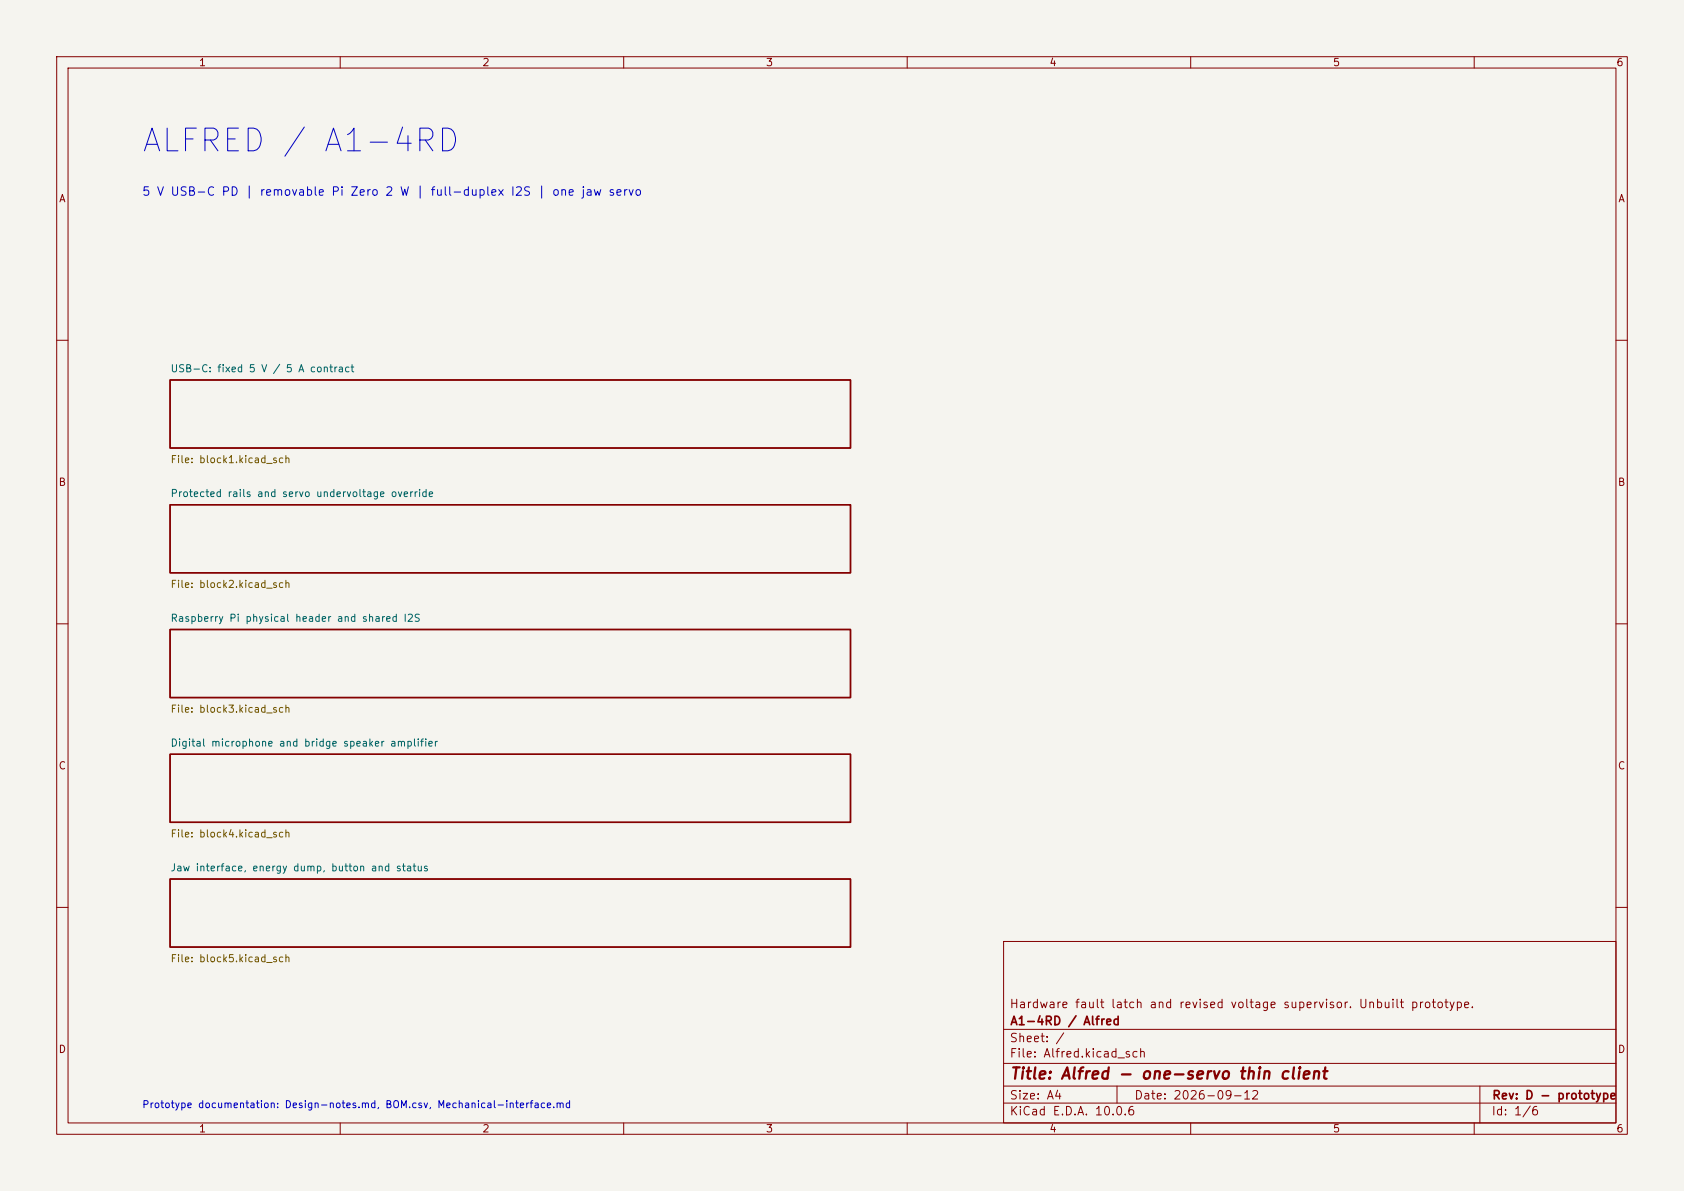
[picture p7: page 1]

Jaw interface, energy dump, button and status File: block5.kicad_sch ALFRED / A1-4RD

5 V USB-C PD | removable Pi Zero 2 W | full-duplex I2S | one jaw servo

File: block2.kicad_sch USB-C: fixed 5 V / 5 A contract File: block1.kicad_sch Digital microphone and bridge speaker amplifier File: block4.kicad_sch

File: block3.kicad_sch Protected rails and servo undervoltage override

Raspberry Pi physical header and shared I2S

Hardware fault latch and revised voltage supervisor. Unbuilt prototype.
A1-4RD / Alfred
Sheet: /
File: Alfred.kicad_sch
Title: Alfred - one-servo thin client

Size: A4 | Rev: D - prototype
KiCad E.D.A. 10.0.6 | Id: 1/6

Prototype documentation: Design-notes.md, BOM.csv, Mechanical-interface.md

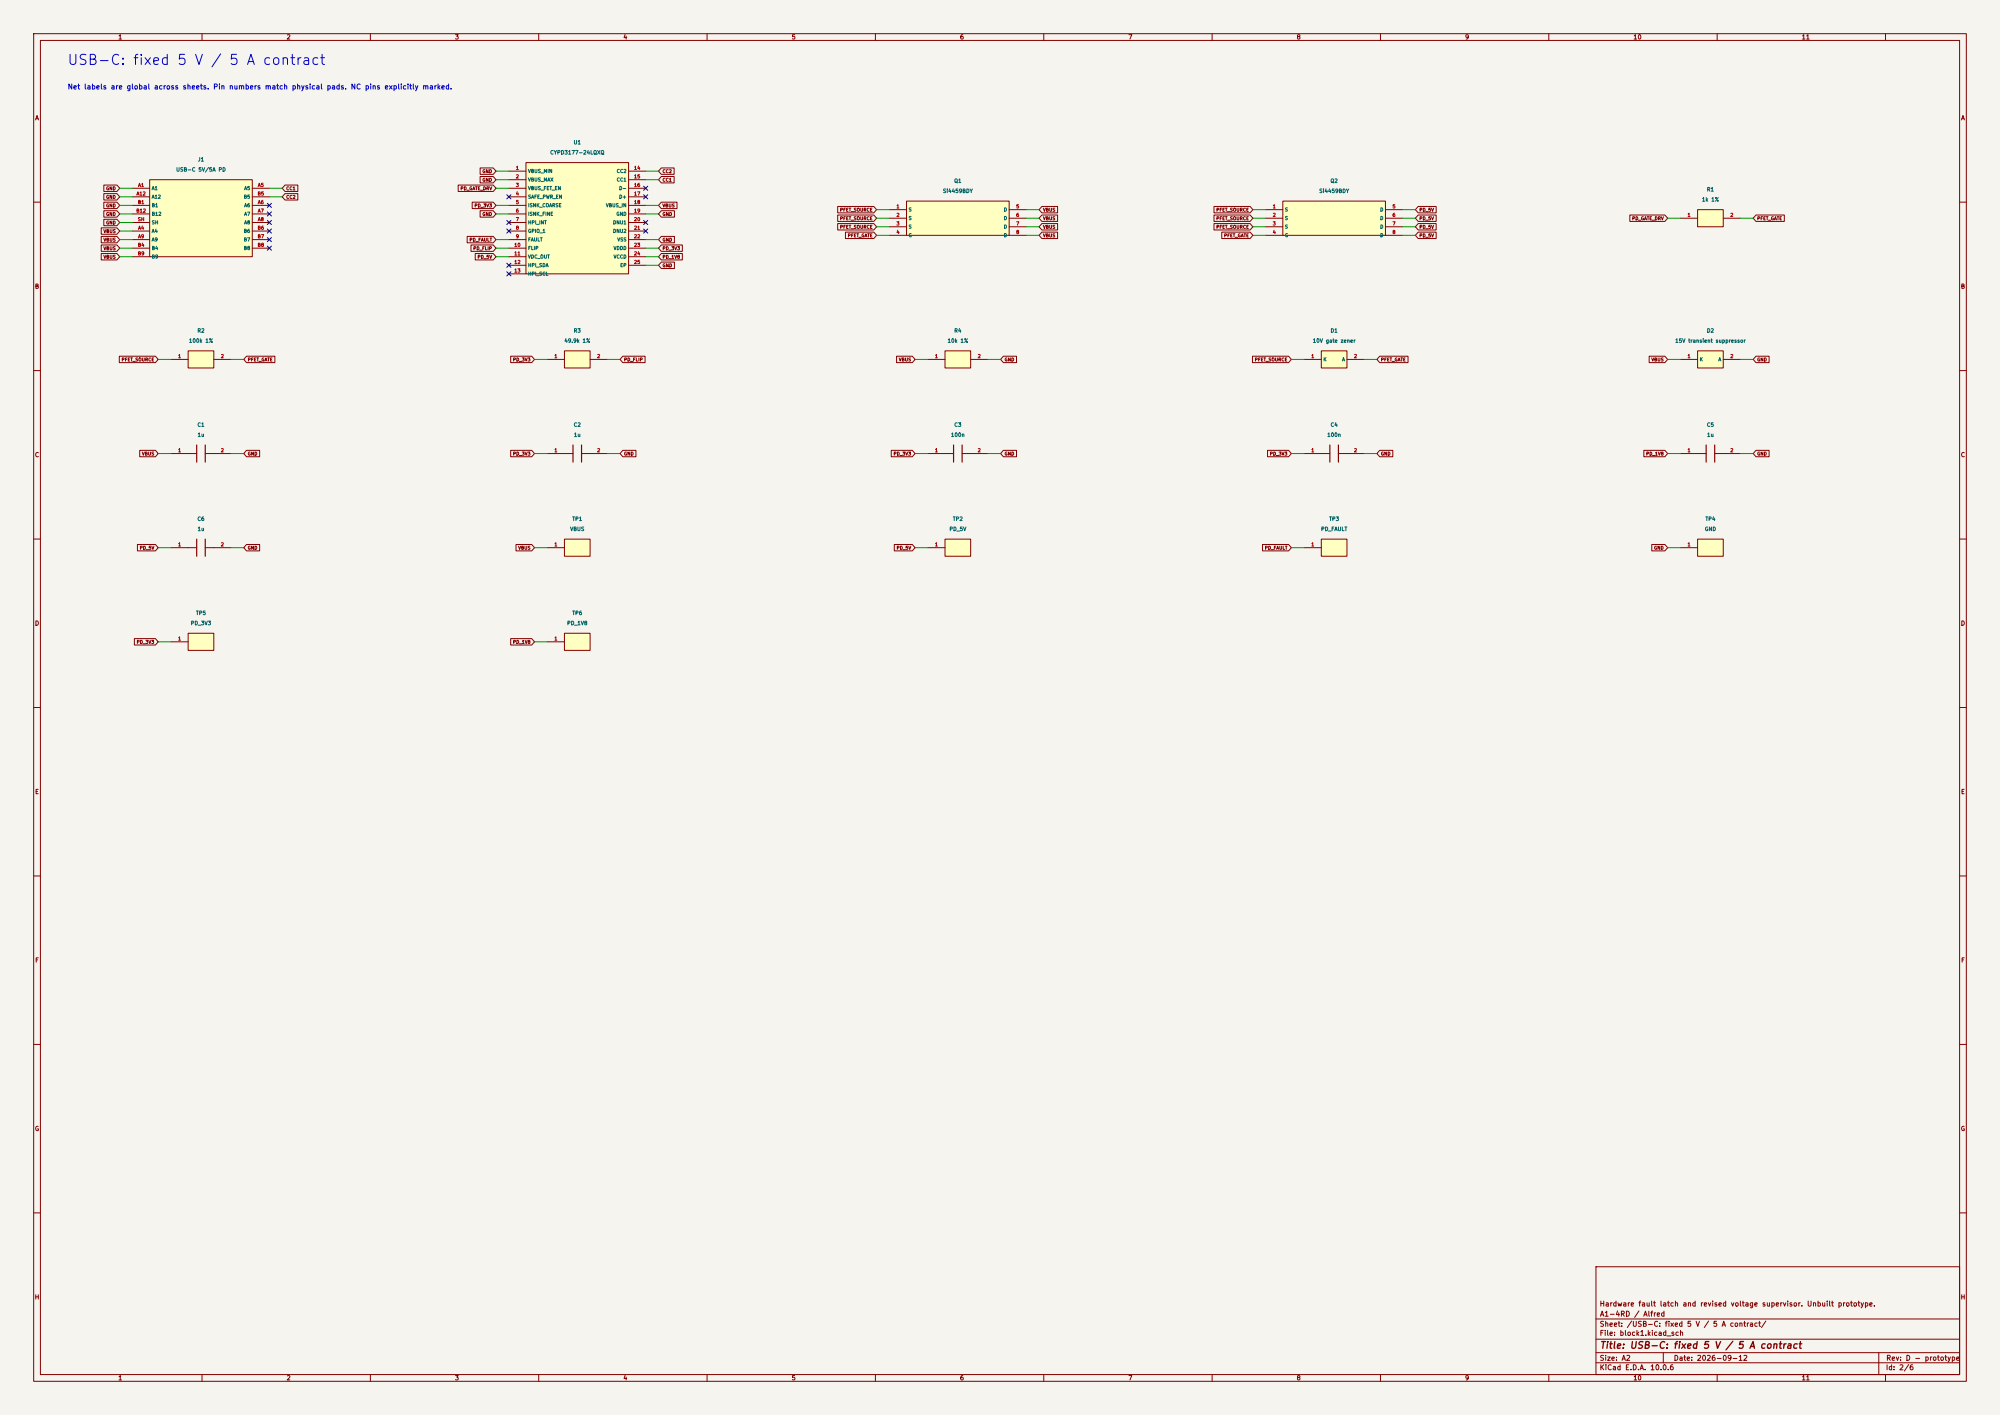
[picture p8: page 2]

GND Net labels are global across sheets. Pin numbers match physical pads. NC pins explicitly marked.

Hardware fault latch and revised voltage supervisor. Unbuilt prototype.
A1-4RD / Alfred
Sheet: /USB-C: fixed 5 V / 5 A contract/
File: block1.kicad_sch
Title: USB-C: fixed 5 V / 5 A contract

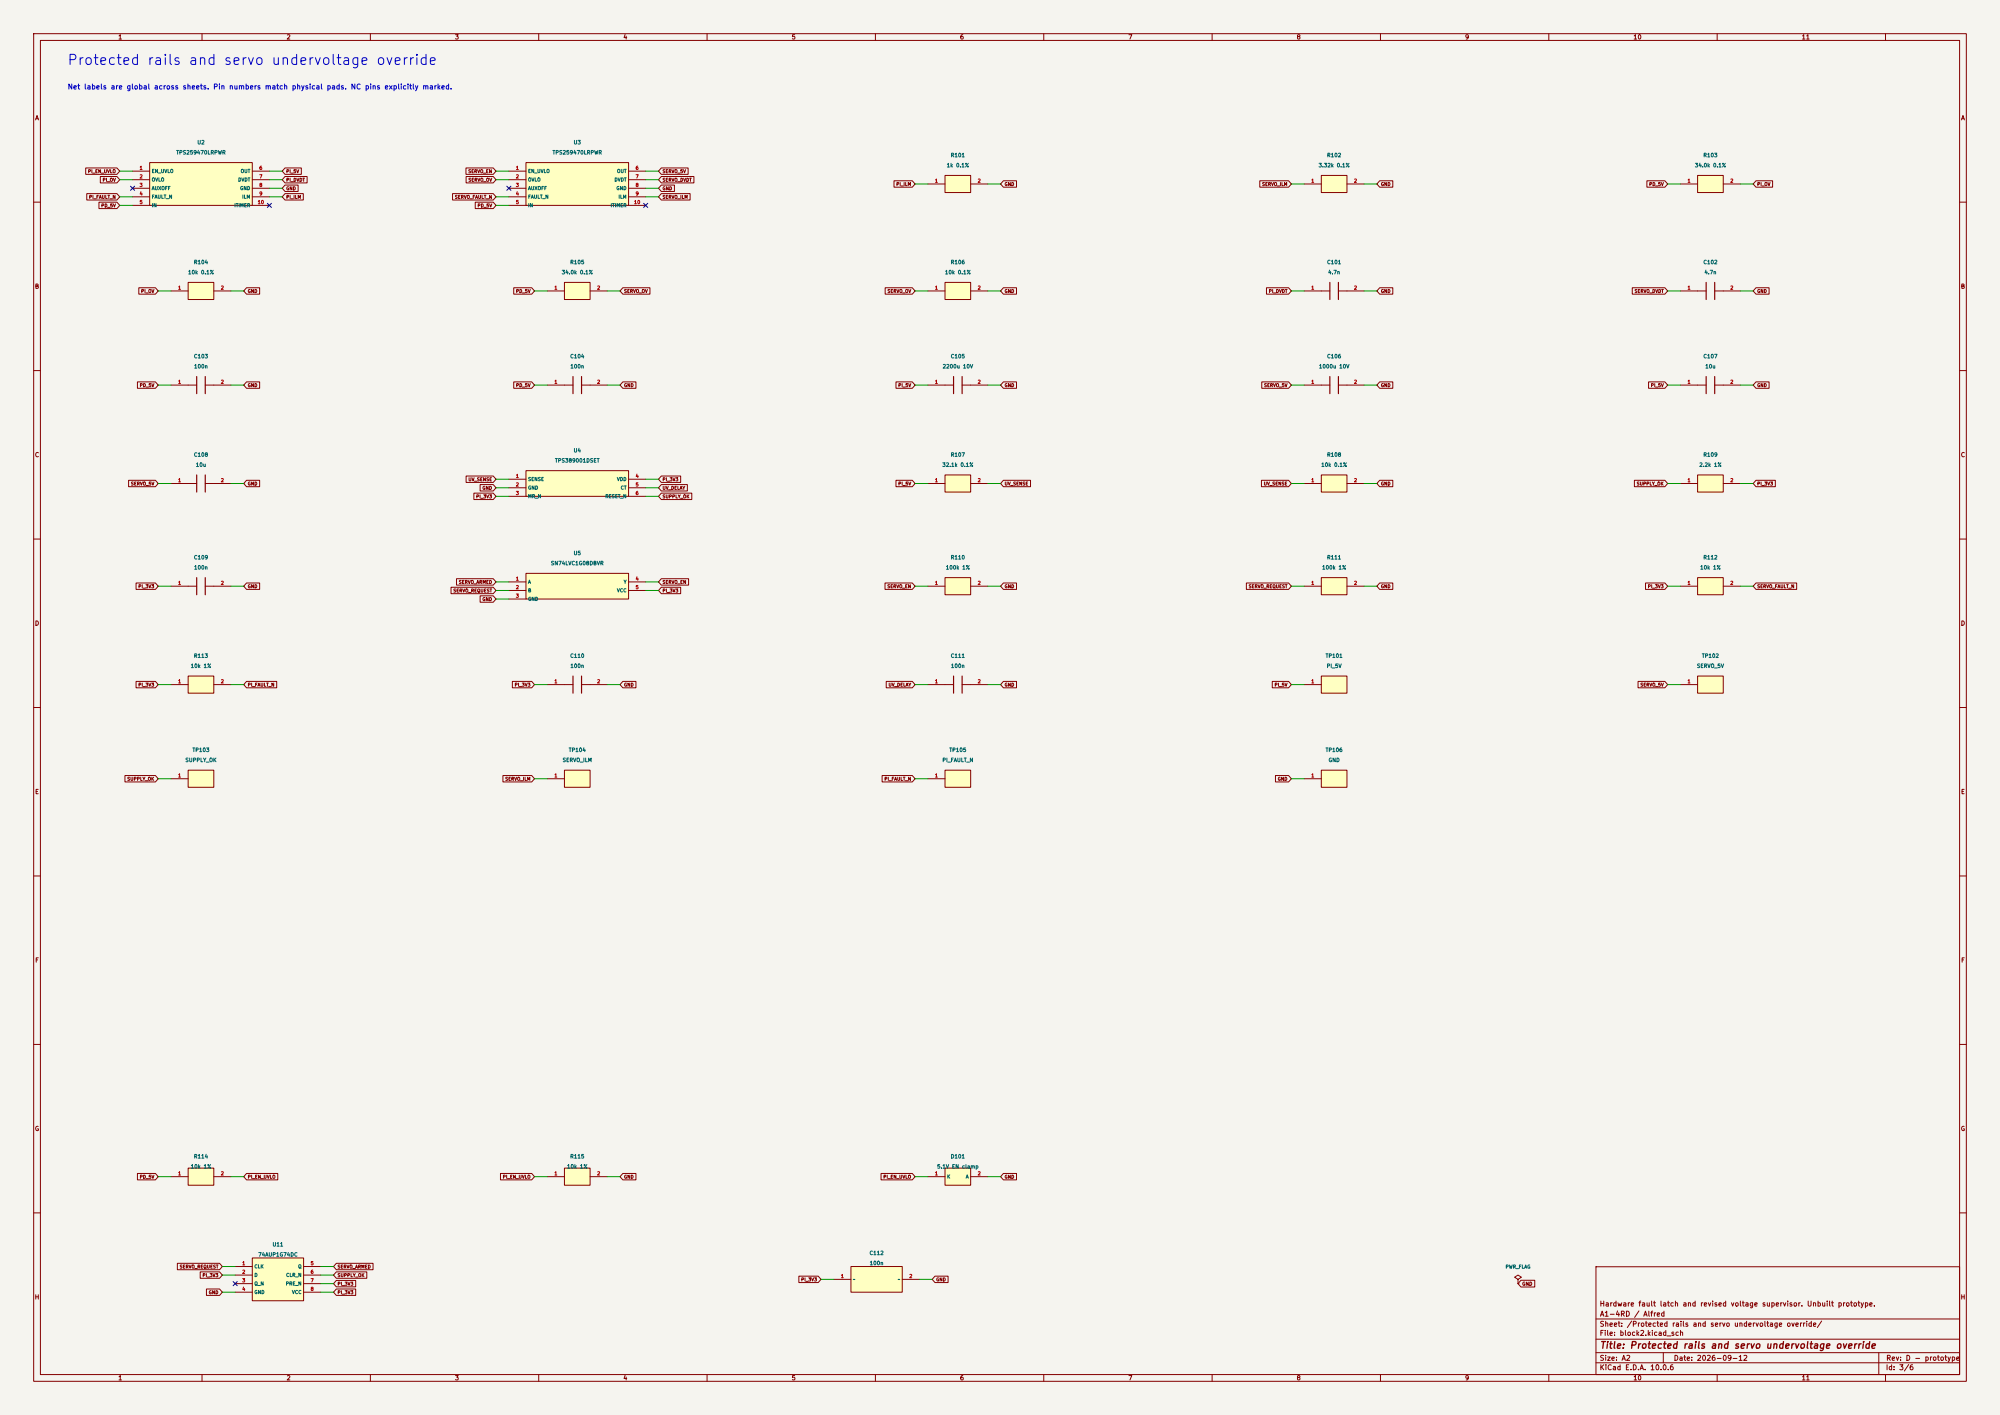
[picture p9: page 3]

SERVO_OV SERVO_OV PD_5V Protected rails and servo undervoltage override

Net labels are global across sheets. Pin numbers match physical pads. NC pins explicitly marked.

Sheet: /Protected rails and servo undervoltage override/
File: block2.kicad_sch
Title: Protected rails and servo undervoltage override

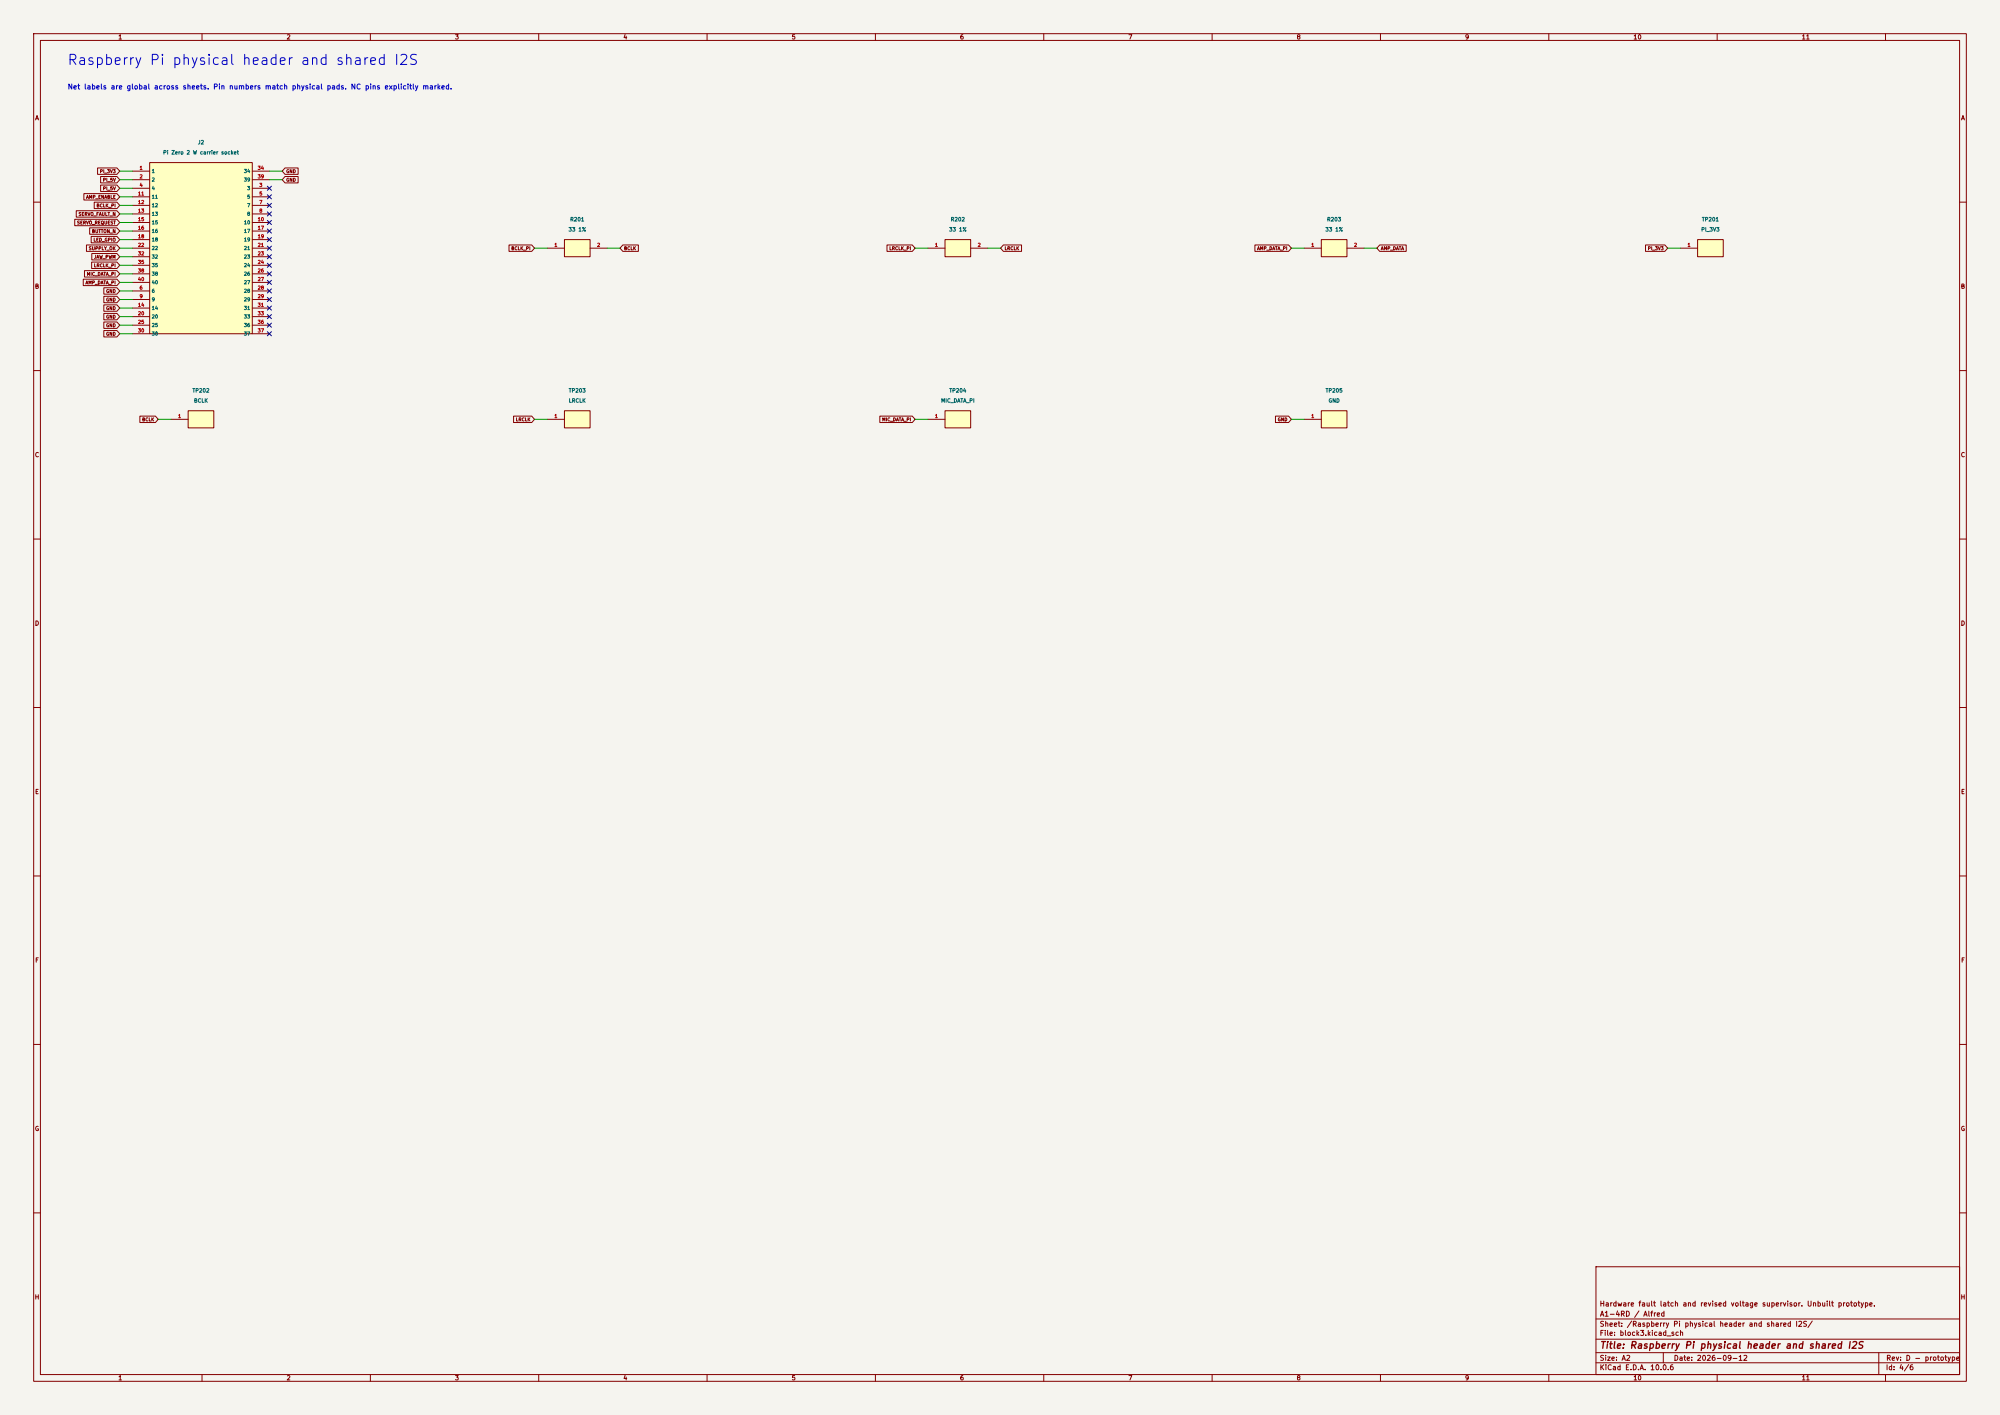
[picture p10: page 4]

AMP_ENABLE SERVO_REQUEST BCLK_PI Raspberry Pi physical header and shared I2S

J2 Pi Zero 2 W carrier socket SERVO_FAULT_N
PI_3V3 PI_5V PI_5V GND

Sheet: /Raspberry Pi physical header and shared I2S/
File: block3.kicad_sch
Title: Raspberry Pi physical header and shared I2S

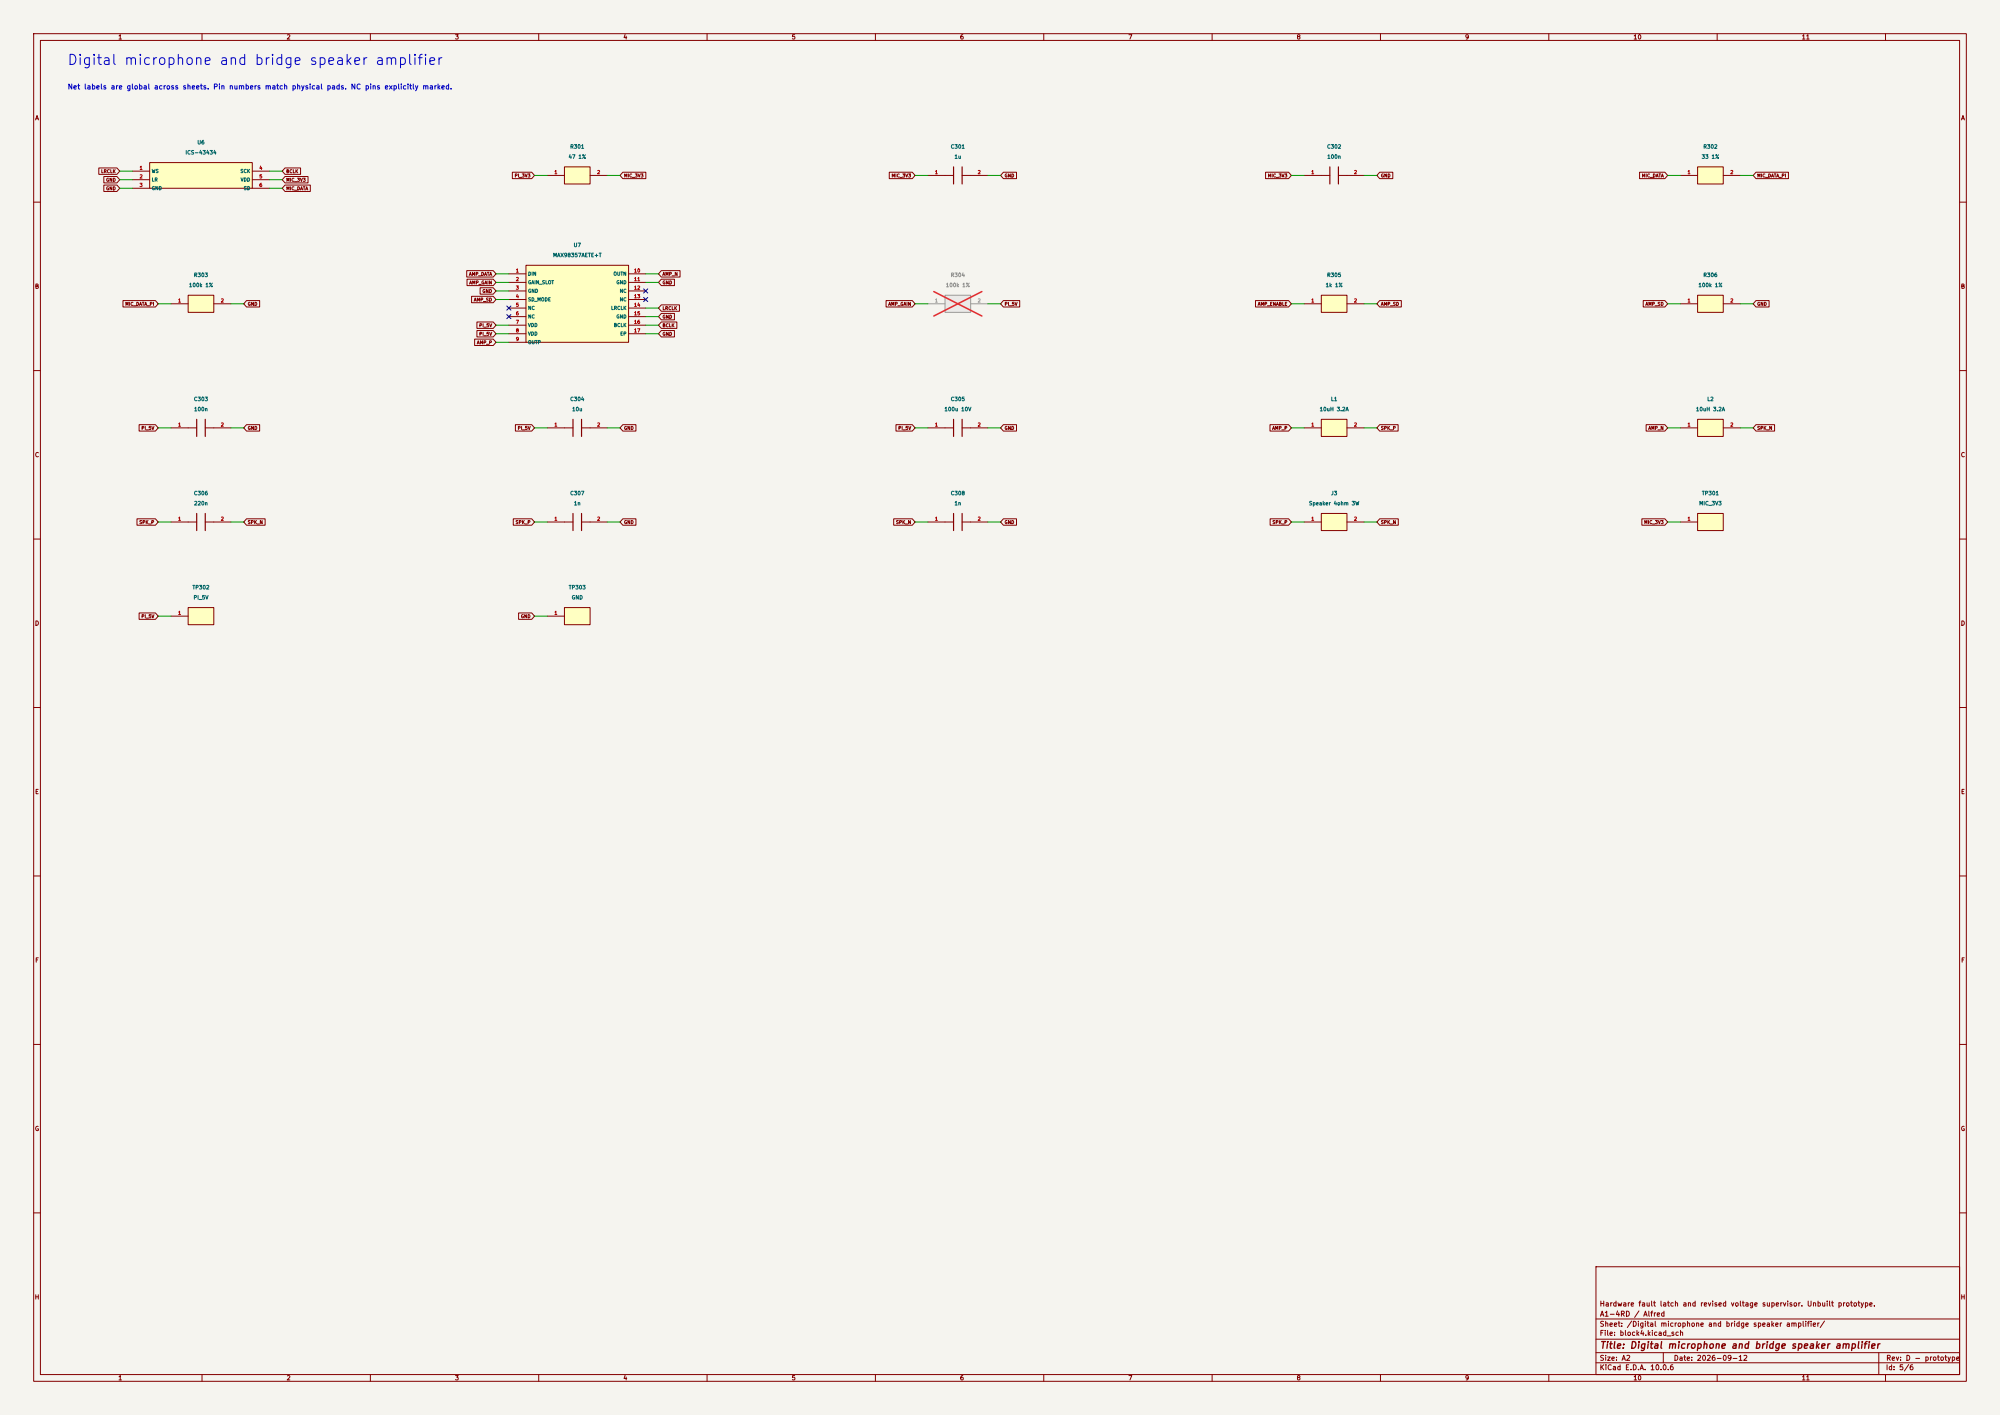
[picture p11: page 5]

Digital microphone and bridge speaker amplifier

Sheet: /Digital microphone and bridge speaker amplifier/
File: block4.kicad_sch
Title: Digital microphone and bridge speaker amplifier

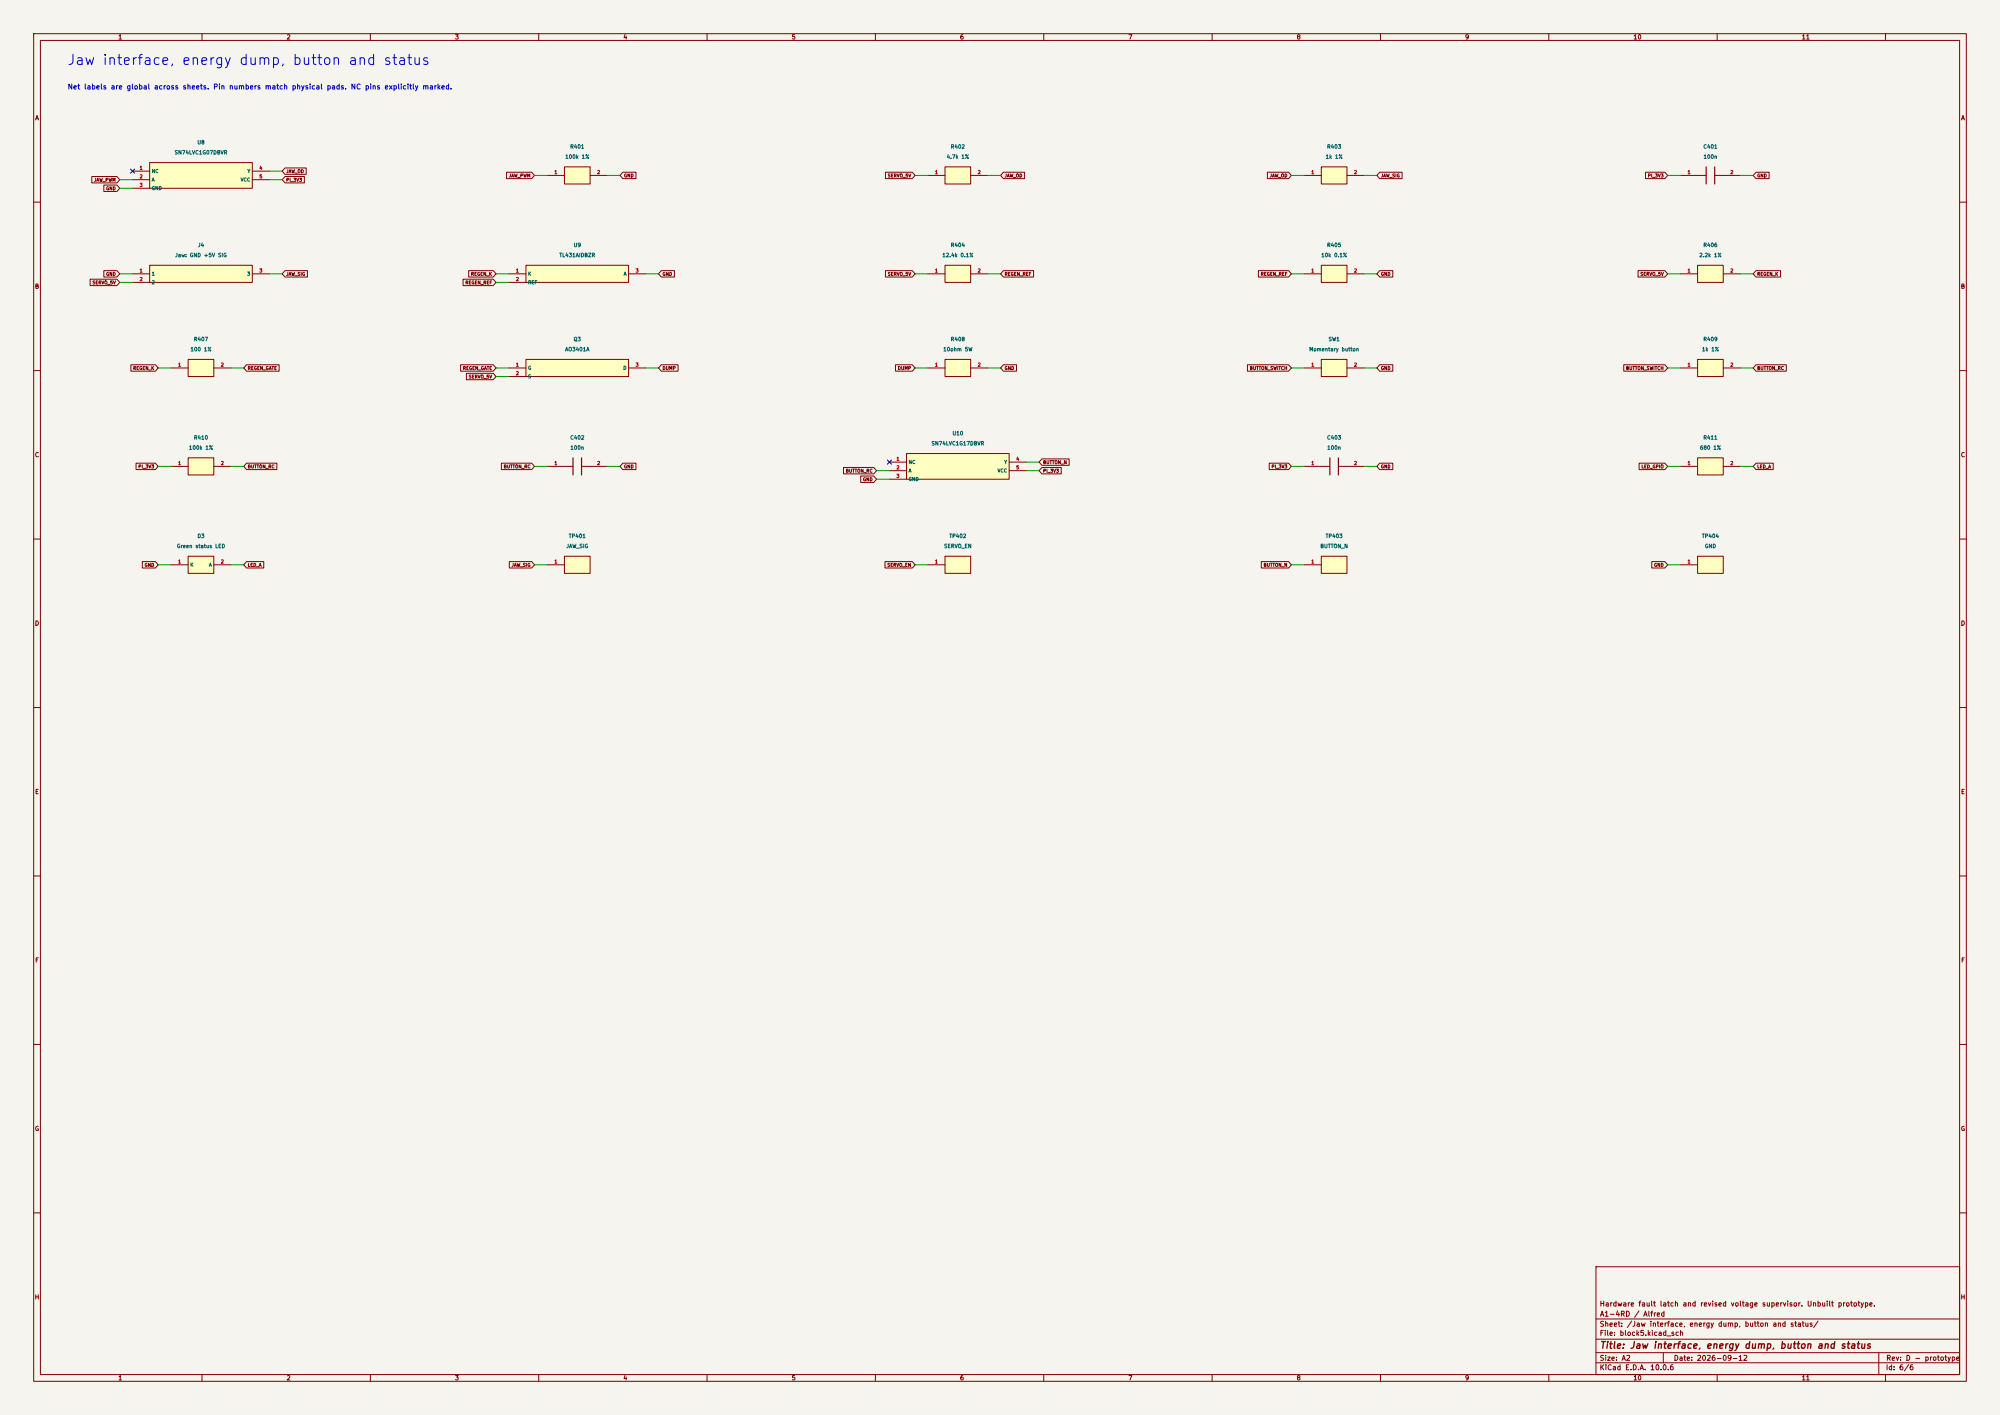
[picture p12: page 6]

JAW_SIG Jaw interface, energy dump, button and status

Sheet: /Jaw interface, energy dump, button and status/
File: block5.kicad_sch
Title: Jaw interface, energy dump, button and status

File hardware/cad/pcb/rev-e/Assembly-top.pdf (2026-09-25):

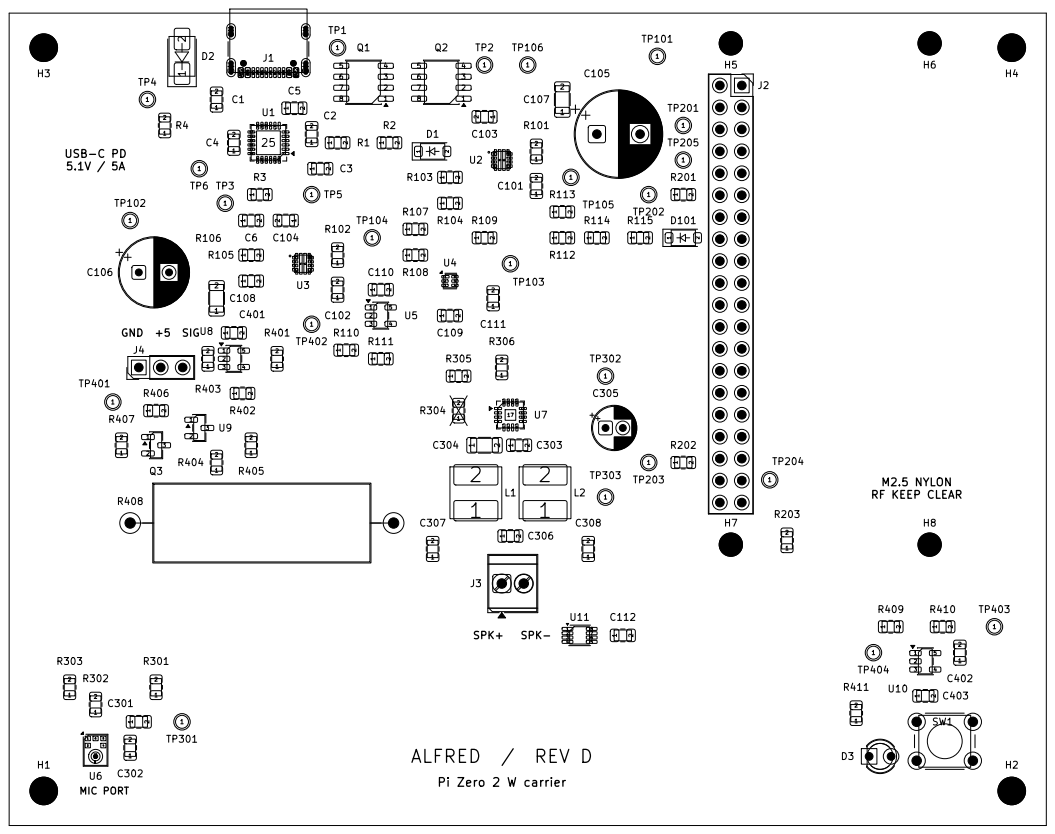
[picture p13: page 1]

RF KEEP CLEAR Pi Zero 2 W carrier ALFRED / REV D

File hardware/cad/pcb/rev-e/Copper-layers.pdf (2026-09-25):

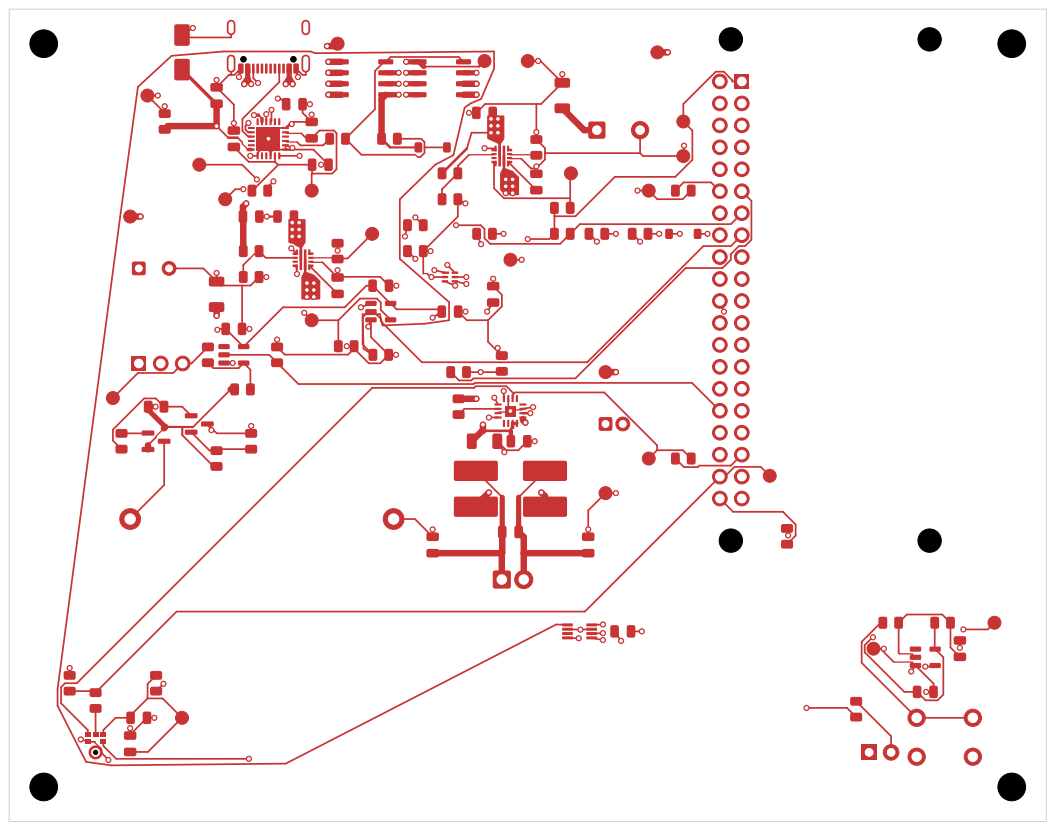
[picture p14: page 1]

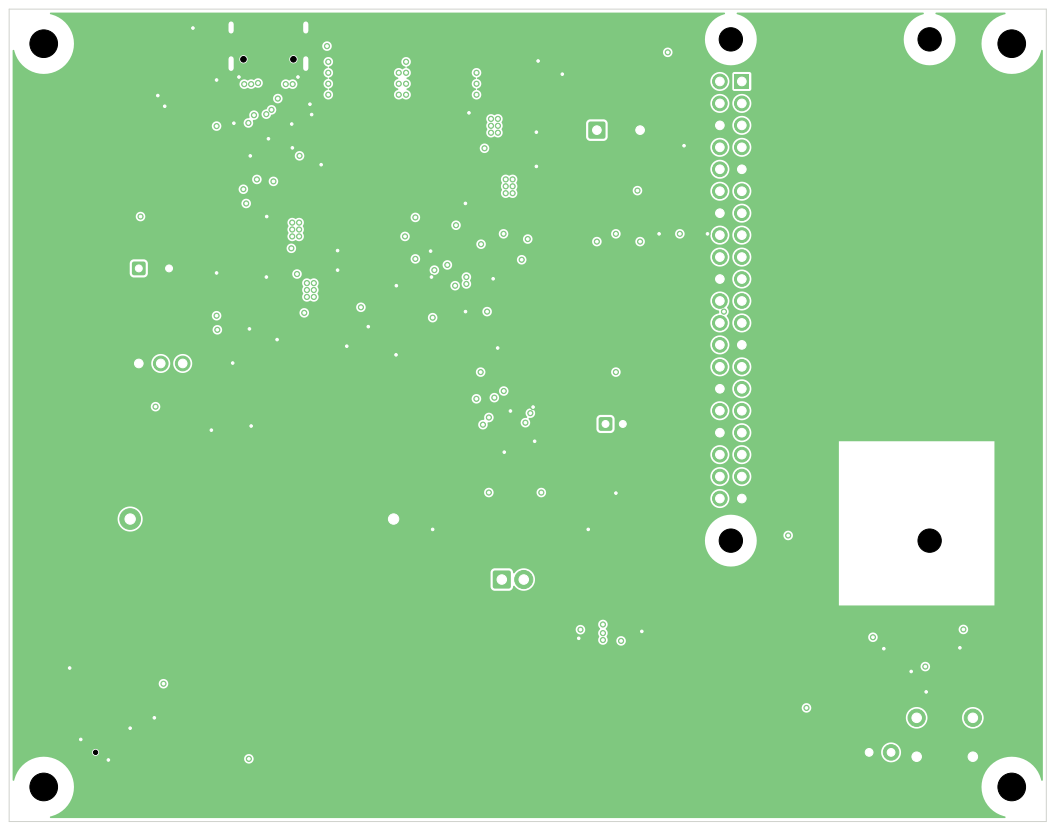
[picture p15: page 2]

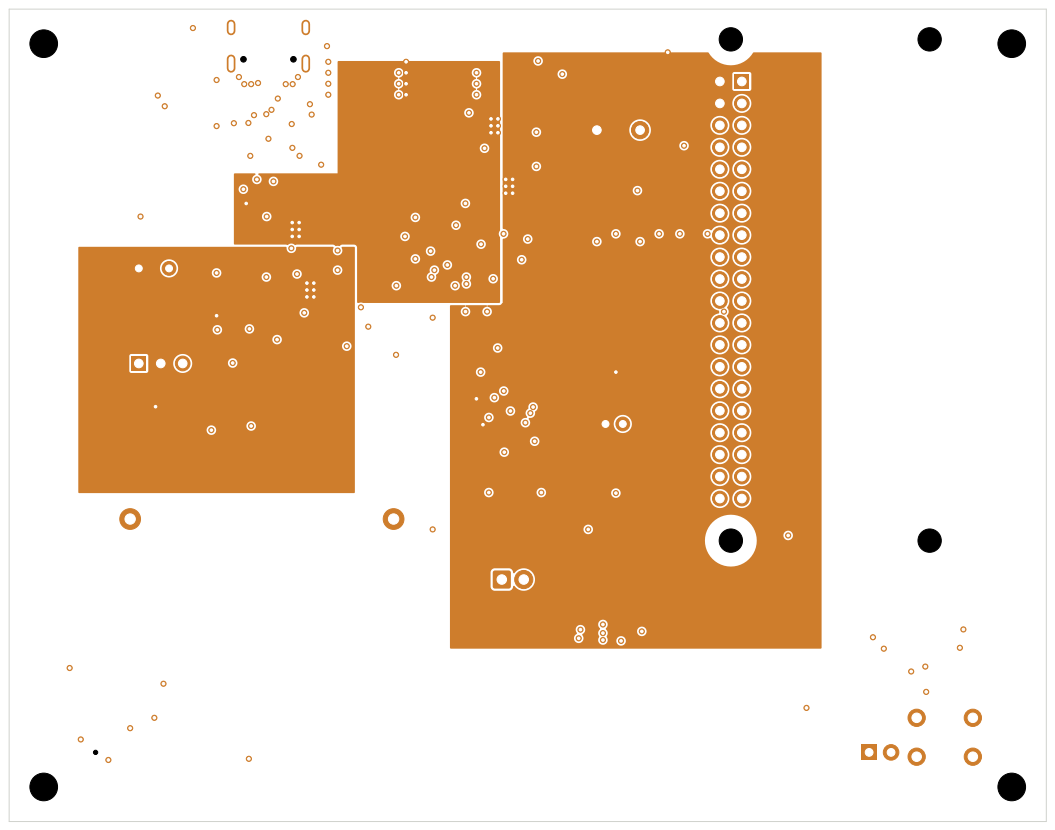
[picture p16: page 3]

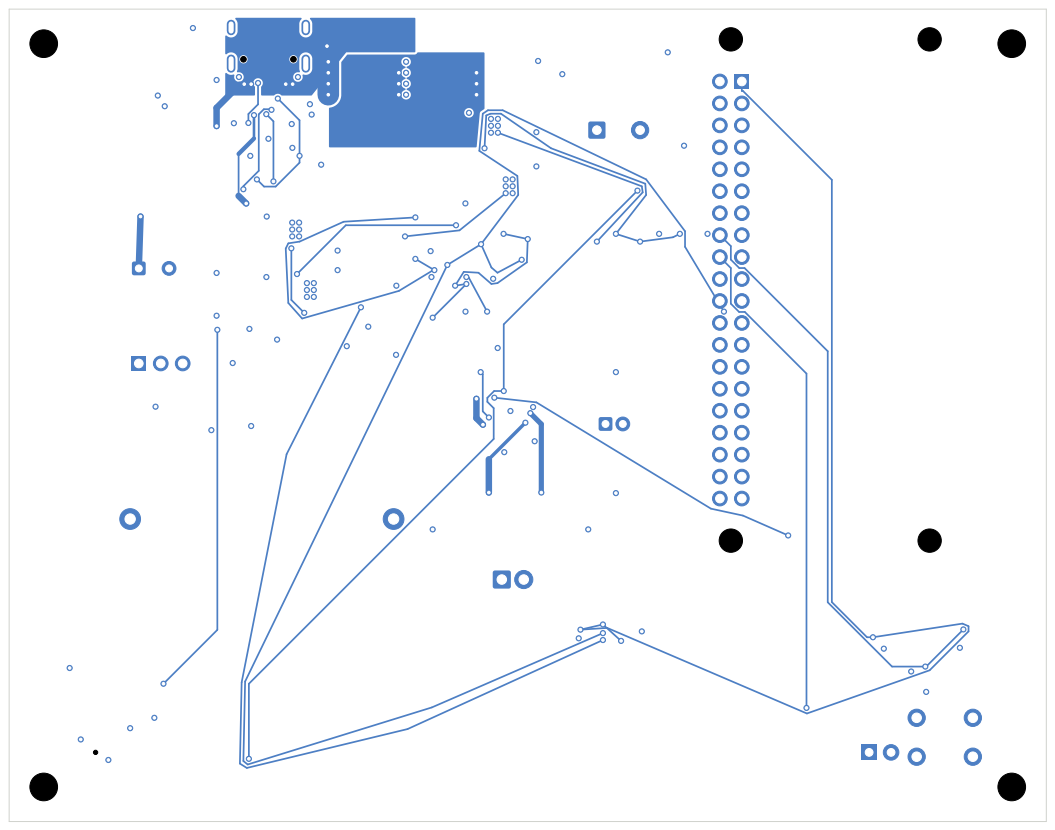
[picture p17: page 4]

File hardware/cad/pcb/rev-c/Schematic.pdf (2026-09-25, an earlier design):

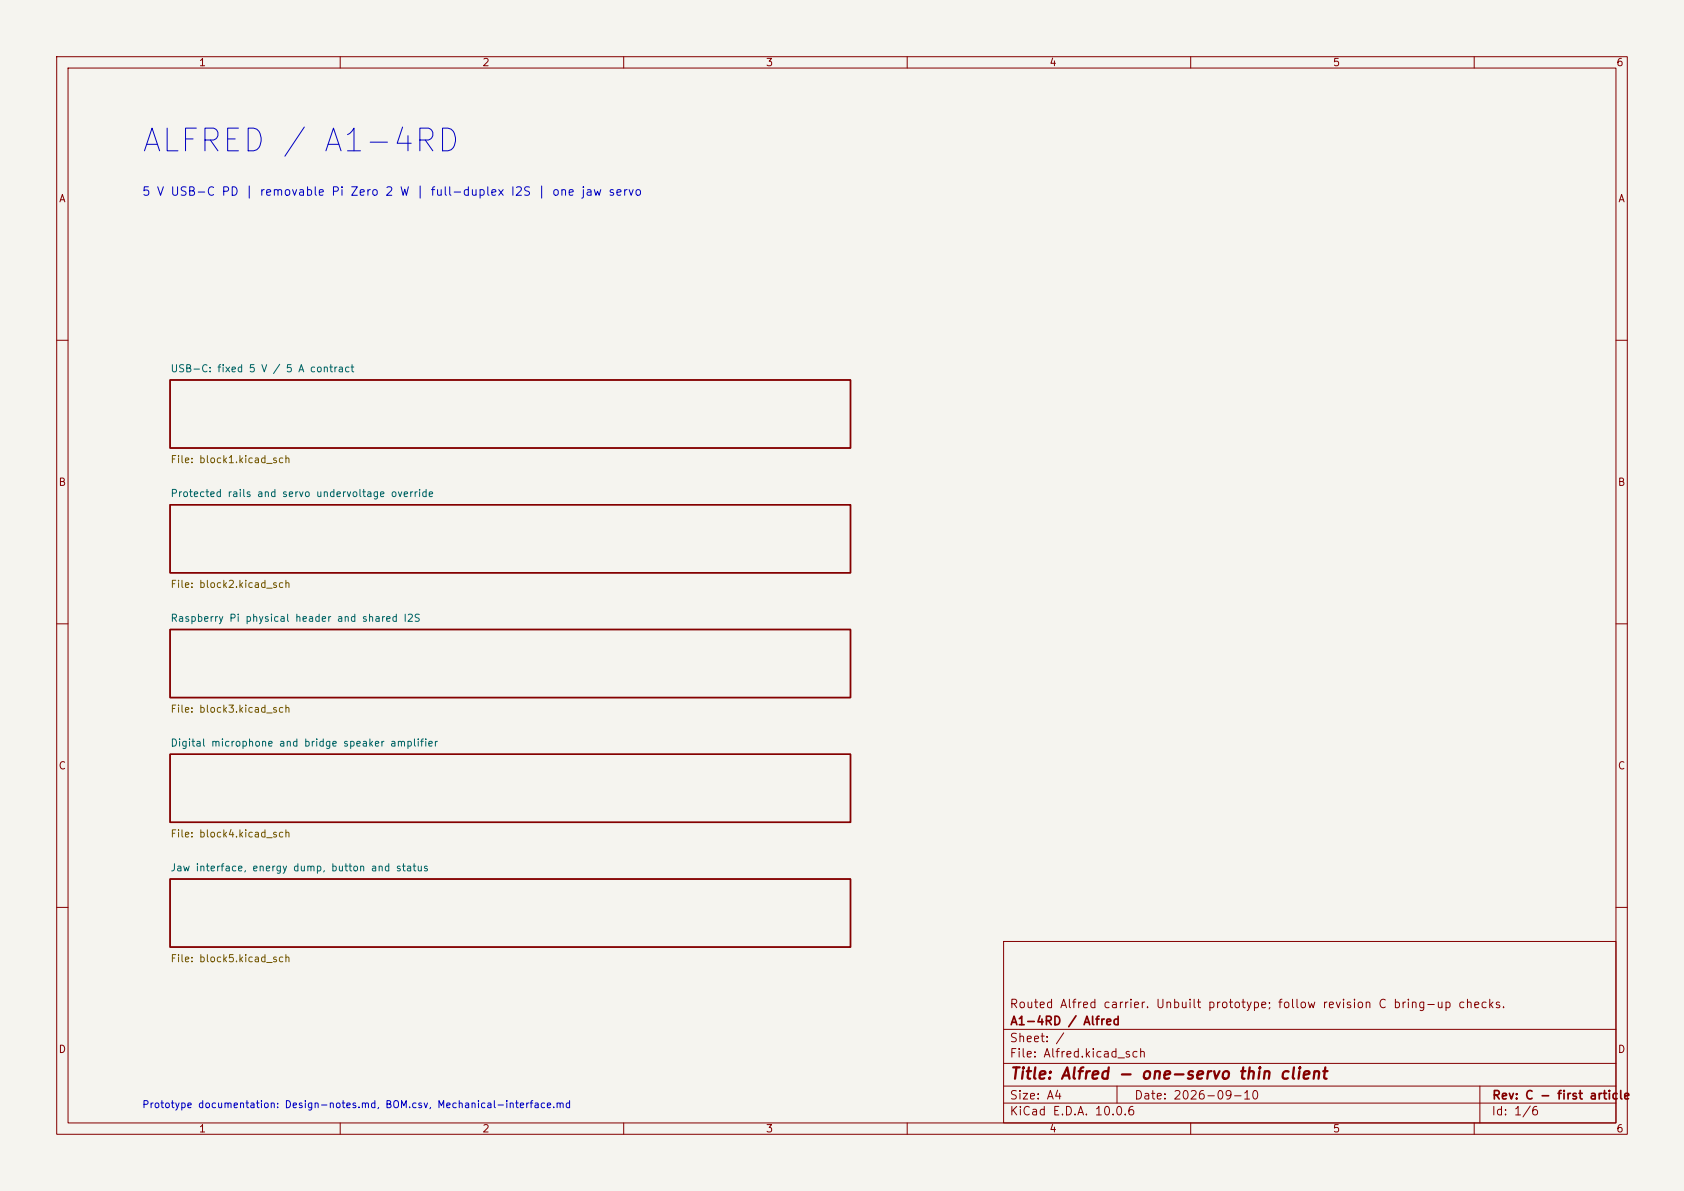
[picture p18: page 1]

Jaw interface, energy dump, button and status File: block5.kicad_sch ALFRED / A1-4RD

5 V USB-C PD | removable Pi Zero 2 W | full-duplex I2S | one jaw servo

File: block2.kicad_sch USB-C: fixed 5 V / 5 A contract File: block1.kicad_sch Digital microphone and bridge speaker amplifier File: block4.kicad_sch

File: block3.kicad_sch Protected rails and servo undervoltage override

Raspberry Pi physical header and shared I2S

Routed Alfred carrier. Unbuilt prototype; follow revision C bring-up checks.
A1-4RD / Alfred
Sheet: /
File: Alfred.kicad_sch
Title: Alfred - one-servo thin client
KiCad E.D.A. 10.0.6

Prototype documentation: Design-notes.md, BOM.csv, Mechanical-interface.md


GND Net labels are global across sheets. Pin numbers match physical pads. NC pins explicitly marked.

Routed Alfred carrier. Unbuilt prototype; follow revision C bring-up checks.
A1-4RD / Alfred
Sheet: /USB-C: fixed 5 V / 5 A contract/
File: block1.kicad_sch
Title: USB-C: fixed 5 V / 5 A contract


Net labels are global across sheets. Pin numbers match physical pads. NC pins explicitly marked.

Sheet: /Protected rails and servo undervoltage override/
File: block2.kicad_sch
Title: Protected rails and servo undervoltage override


AMP_ENABLE SERVO_REQUEST BCLK_PI Raspberry Pi physical header and shared I2S

J2 Pi Zero 2 W carrier socket SERVO_FAULT_N
PI_3V3 PI_5V PI_5V GND

Sheet: /Raspberry Pi physical header and shared I2S/
File: block3.kicad_sch
Title: Raspberry Pi physical header and shared I2S


Digital microphone and bridge speaker amplifier

Sheet: /Digital microphone and bridge speaker amplifier/
File: block4.kicad_sch
Title: Digital microphone and bridge speaker amplifier


JAW_SIG Jaw interface, energy dump, button and status

Sheet: /Jaw interface, energy dump, button and status/
File: block5.kicad_sch
Title: Jaw interface, energy dump, button and status

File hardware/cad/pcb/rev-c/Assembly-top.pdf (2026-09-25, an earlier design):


RF KEEP CLEAR Pi Zero 2 W carrier ALFRED / REV C





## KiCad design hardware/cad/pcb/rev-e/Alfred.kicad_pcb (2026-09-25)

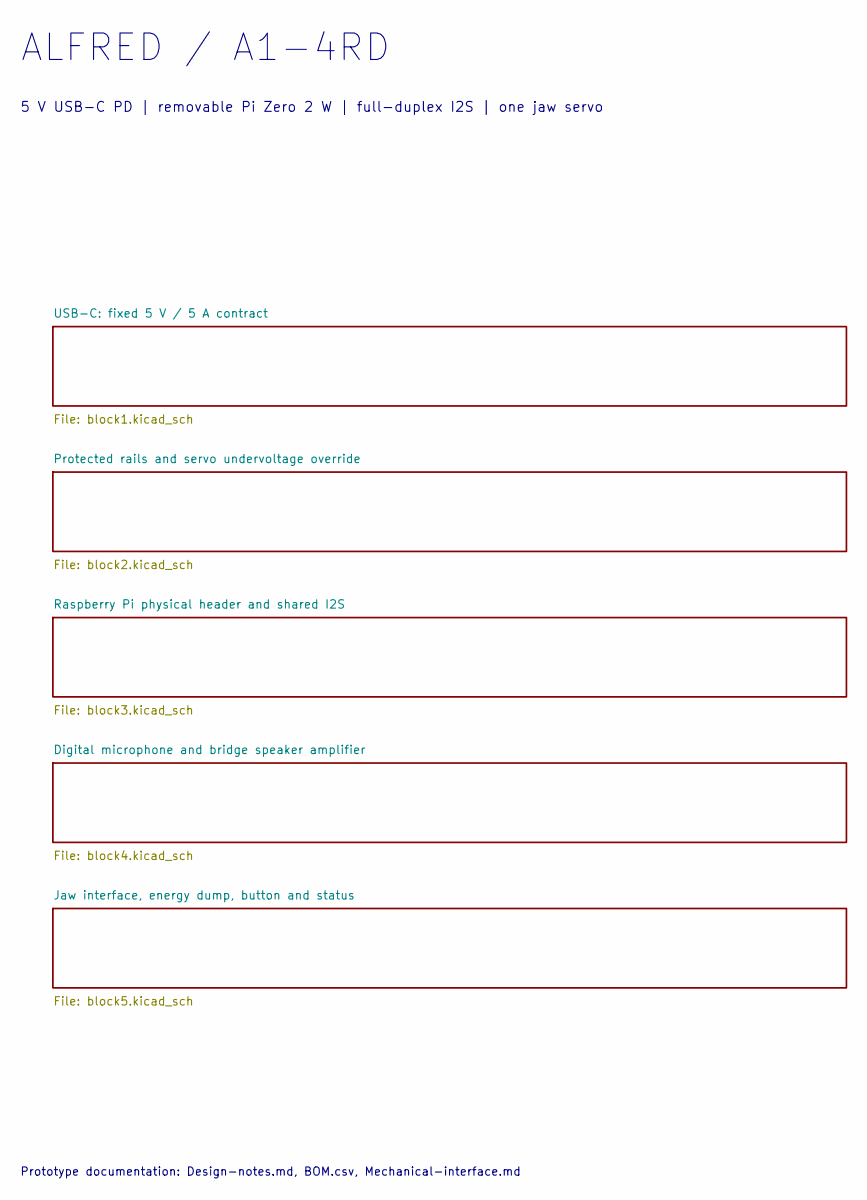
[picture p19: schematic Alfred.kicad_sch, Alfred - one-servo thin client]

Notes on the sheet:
ALFRED / A1-4RD
Prototype documentation: Design-notes.md, BOM.csv, Mechanical-interface.md
5 V USB-C PD | removable Pi Zero 2 W | full-duplex I2S | one jaw servo

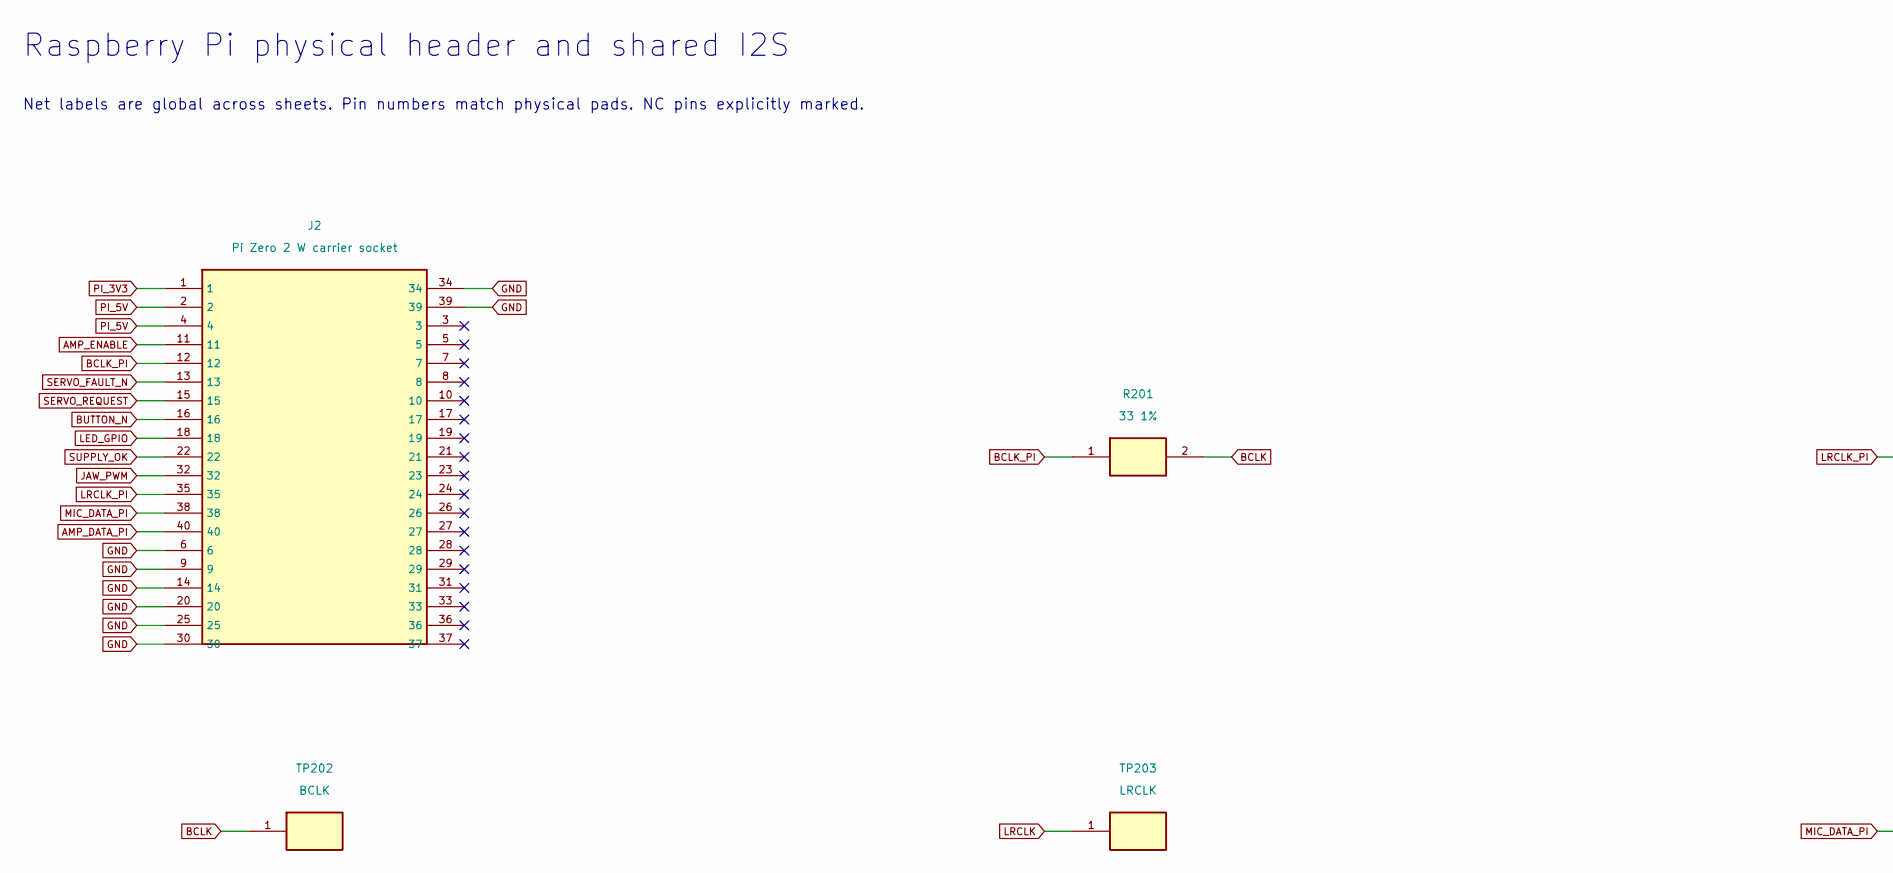
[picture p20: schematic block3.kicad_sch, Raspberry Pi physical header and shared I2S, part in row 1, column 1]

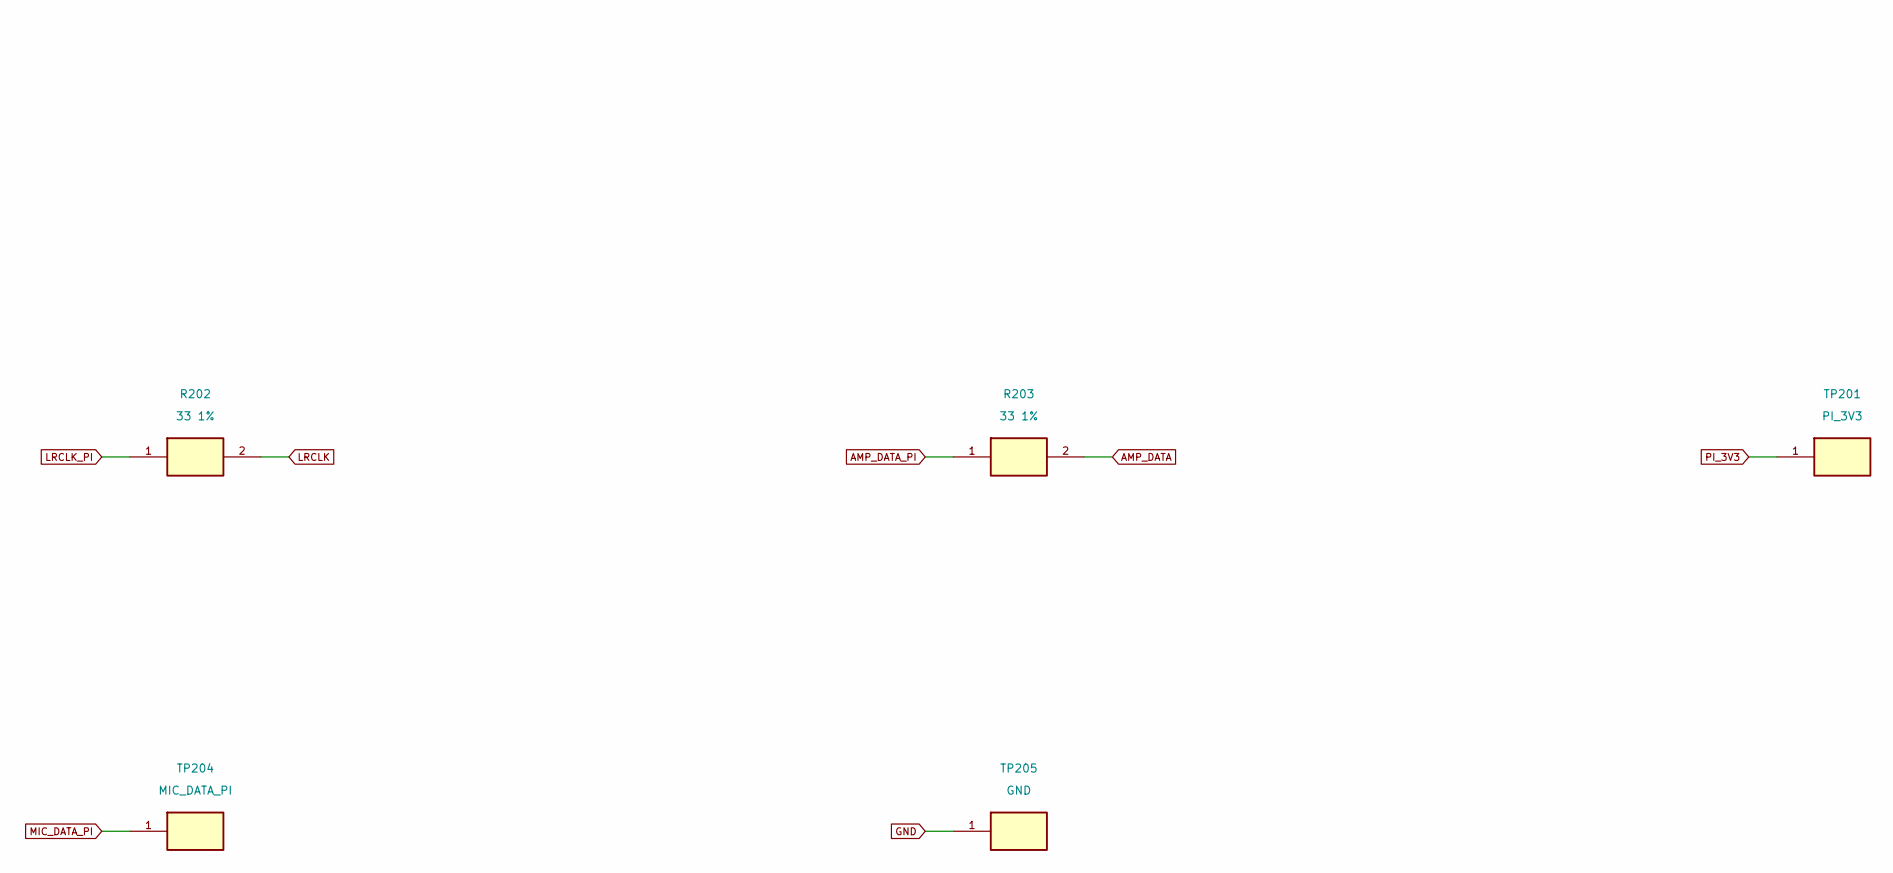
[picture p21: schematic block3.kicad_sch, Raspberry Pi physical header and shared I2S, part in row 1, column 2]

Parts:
J2: Pi Zero 2 W carrier socket; PinSocket_2x20_P2.54mm_Vertical; MPN SSW-120-01-G-D
R201, R202, R203: 33 1%; R_0805_2012Metric; MPN RC0805FR-0733RL
TP201: PI_3V3; TestPoint_Pad_D1.5mm; MPN PCB copper test point
TP202: BCLK; TestPoint_Pad_D1.5mm; MPN PCB copper test point
TP203: LRCLK; TestPoint_Pad_D1.5mm; MPN PCB copper test point
TP204: MIC_DATA_PI; TestPoint_Pad_D1.5mm; MPN PCB copper test point
TP205: GND; TestPoint_Pad_D1.5mm; MPN PCB copper test point

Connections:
AMP_DATA: R203.2; also elsewhere on the board
AMP_DATA_PI: J2.40, R203.1
AMP_ENABLE: J2.11; also elsewhere on the board
BCLK: R201.2, TP202.1; also elsewhere on the board
BCLK_PI: J2.12, R201.1
BUTTON_N: J2.16; also elsewhere on the board
GND: J2.6, J2.9, J2.14, J2.20, J2.25, J2.30, J2.34, J2.39, TP205.1; also elsewhere on the board
JAW_PWM: J2.32; also elsewhere on the board
LED_GPIO: J2.18; also elsewhere on the board
LRCLK: R202.2, TP203.1; also elsewhere on the board
LRCLK_PI: J2.35, R202.1
MIC_DATA_PI: J2.38, TP204.1; also elsewhere on the board
PI_3V3: J2.1, TP201.1; also elsewhere on the board
PI_5V: J2.2, J2.4; also elsewhere on the board
SERVO_FAULT_N: J2.13; also elsewhere on the board
SERVO_REQUEST: J2.15; also elsewhere on the board
SUPPLY_OK: J2.22; also elsewhere on the board

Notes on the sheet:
Net labels are global across sheets. Pin numbers match physical pads. NC pins explicitly marked.
Raspberry Pi physical header and shared I2S

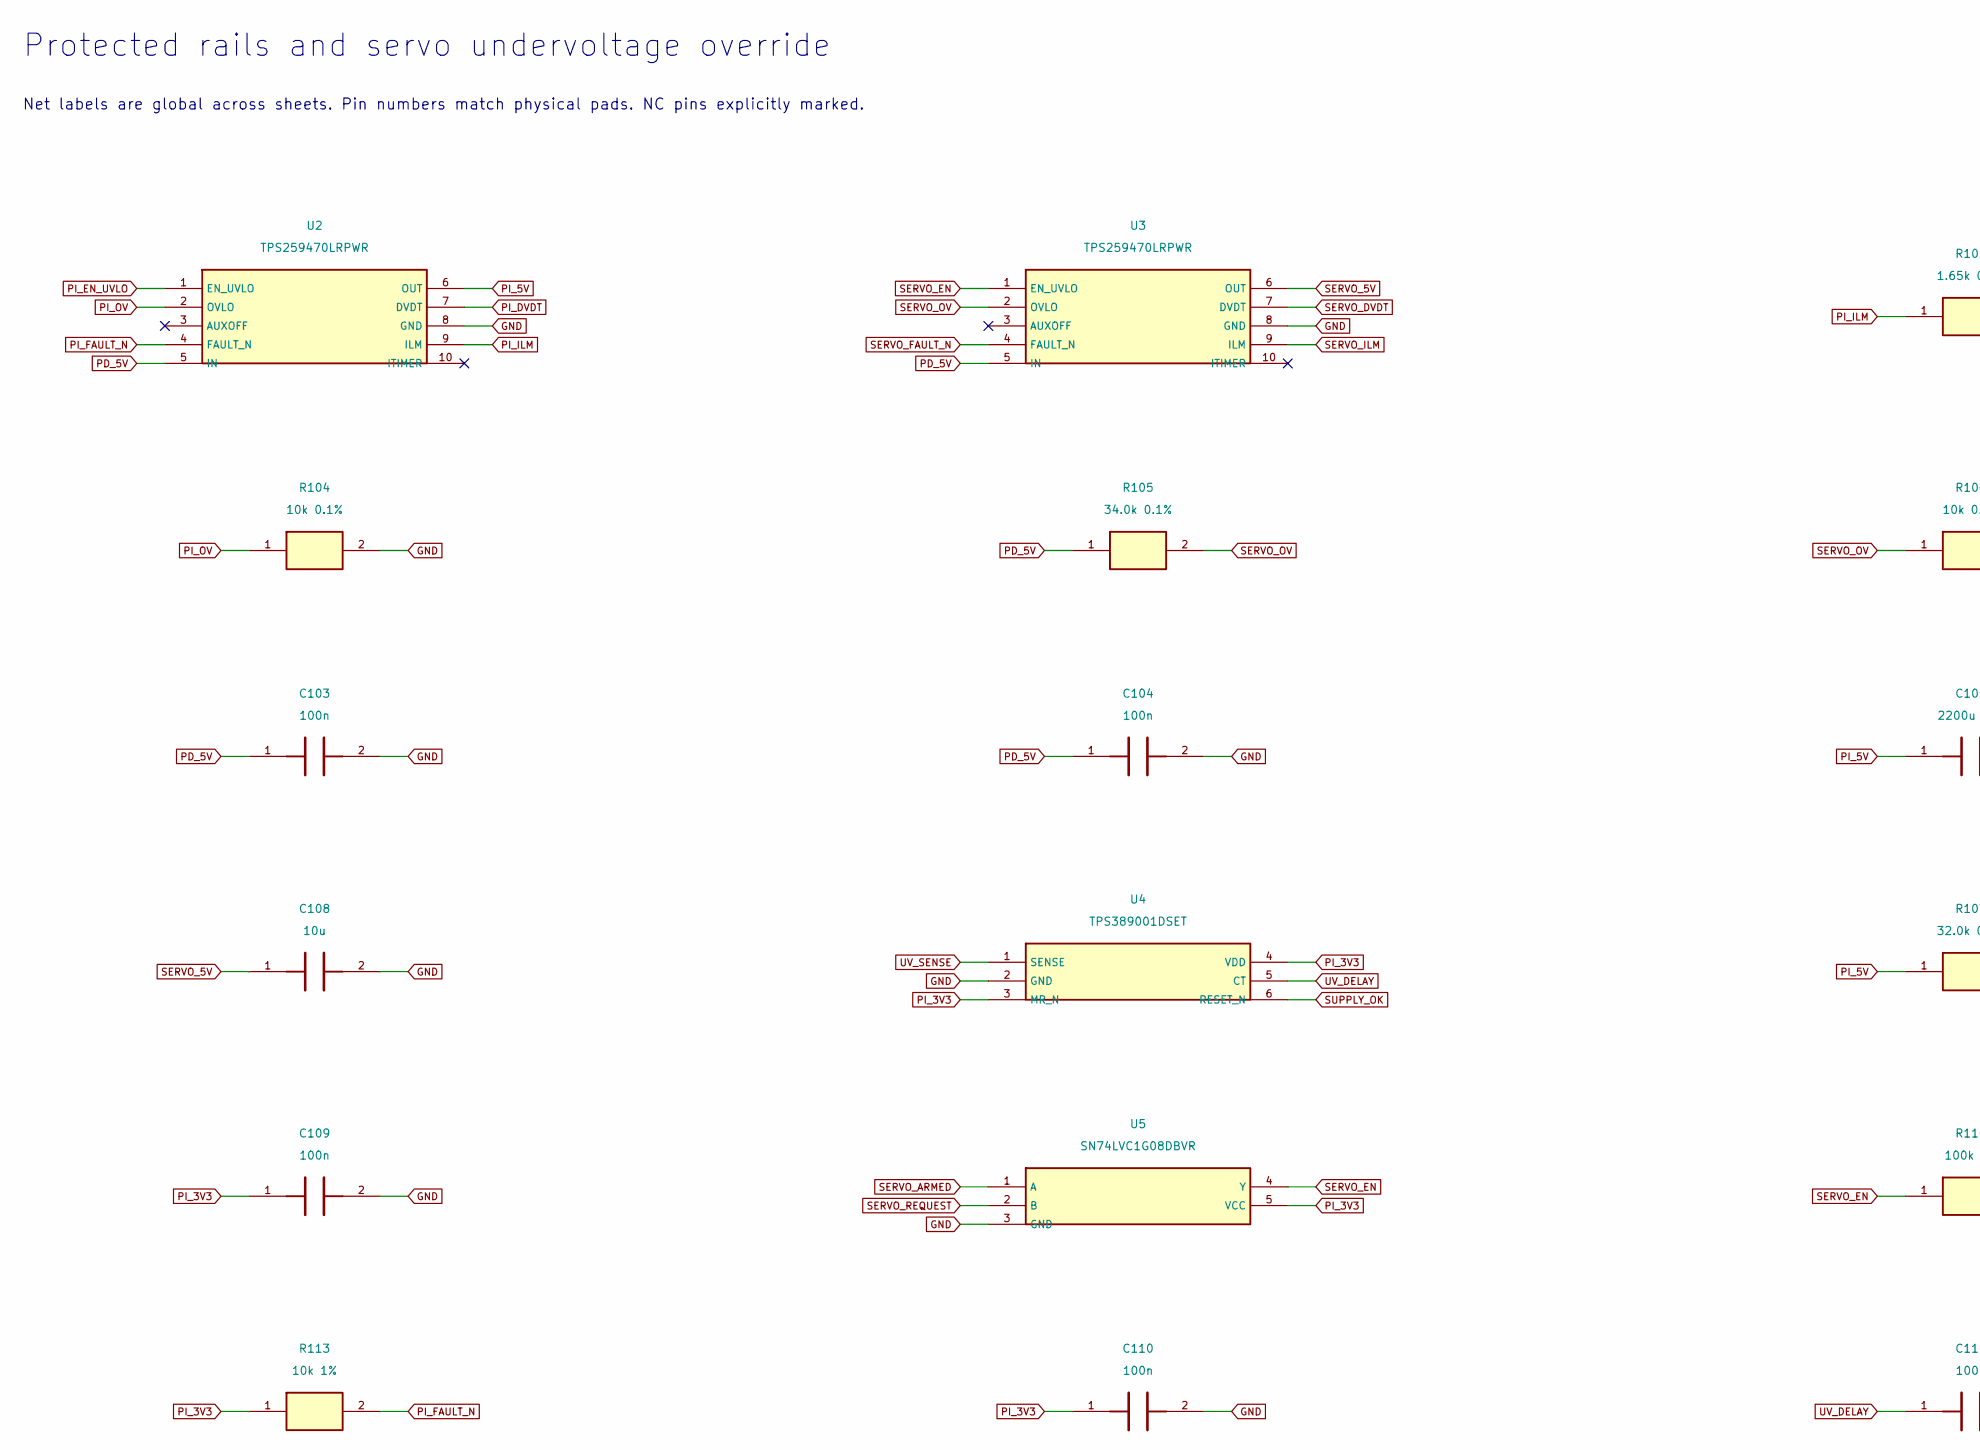
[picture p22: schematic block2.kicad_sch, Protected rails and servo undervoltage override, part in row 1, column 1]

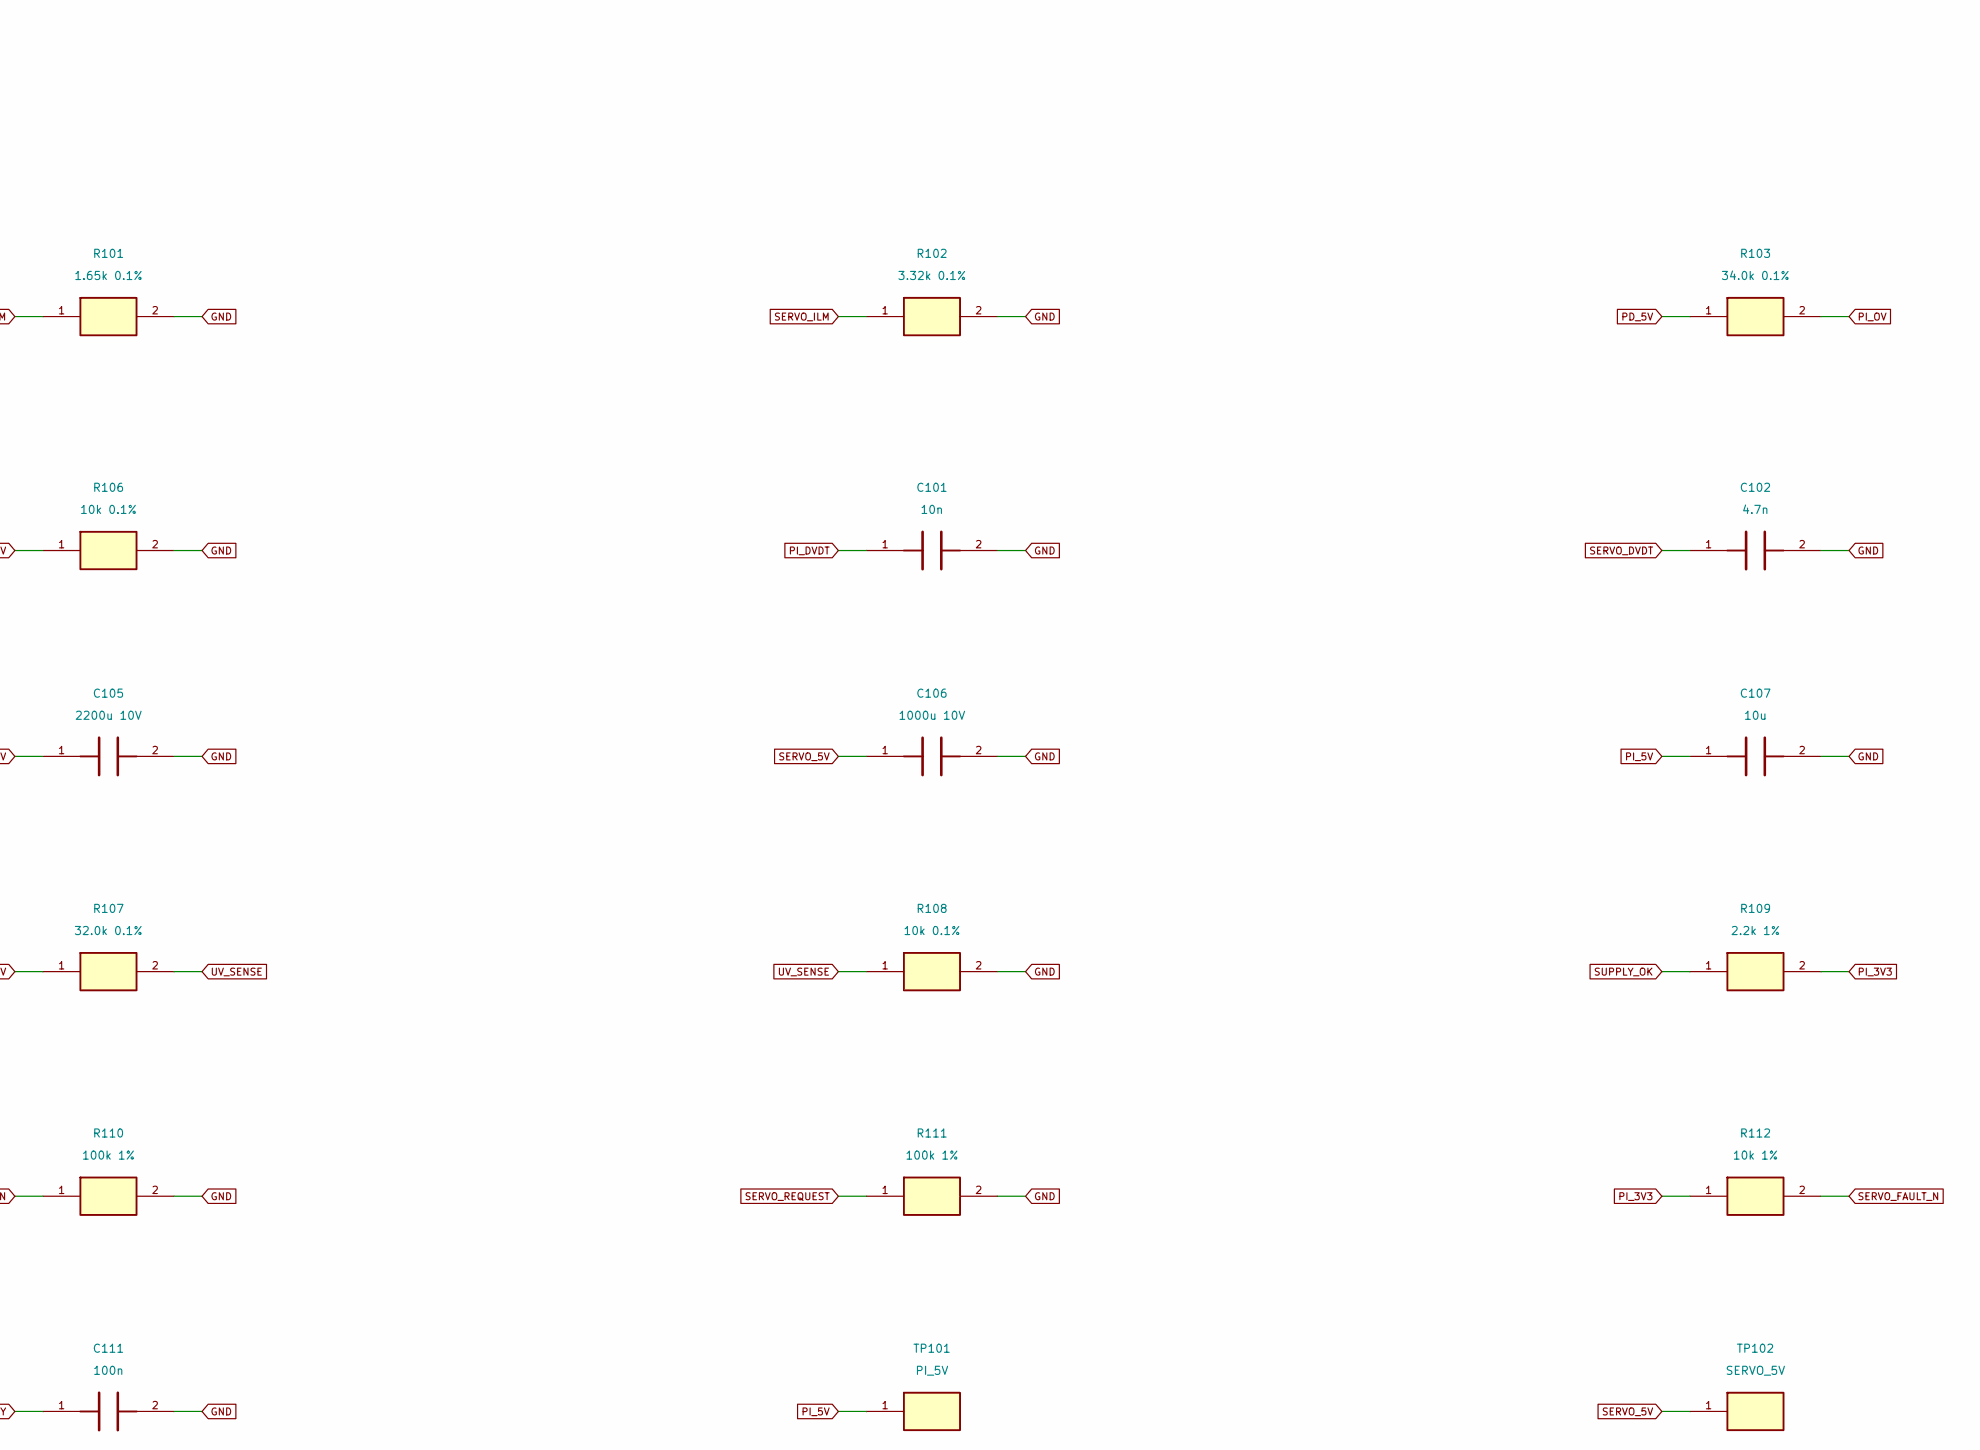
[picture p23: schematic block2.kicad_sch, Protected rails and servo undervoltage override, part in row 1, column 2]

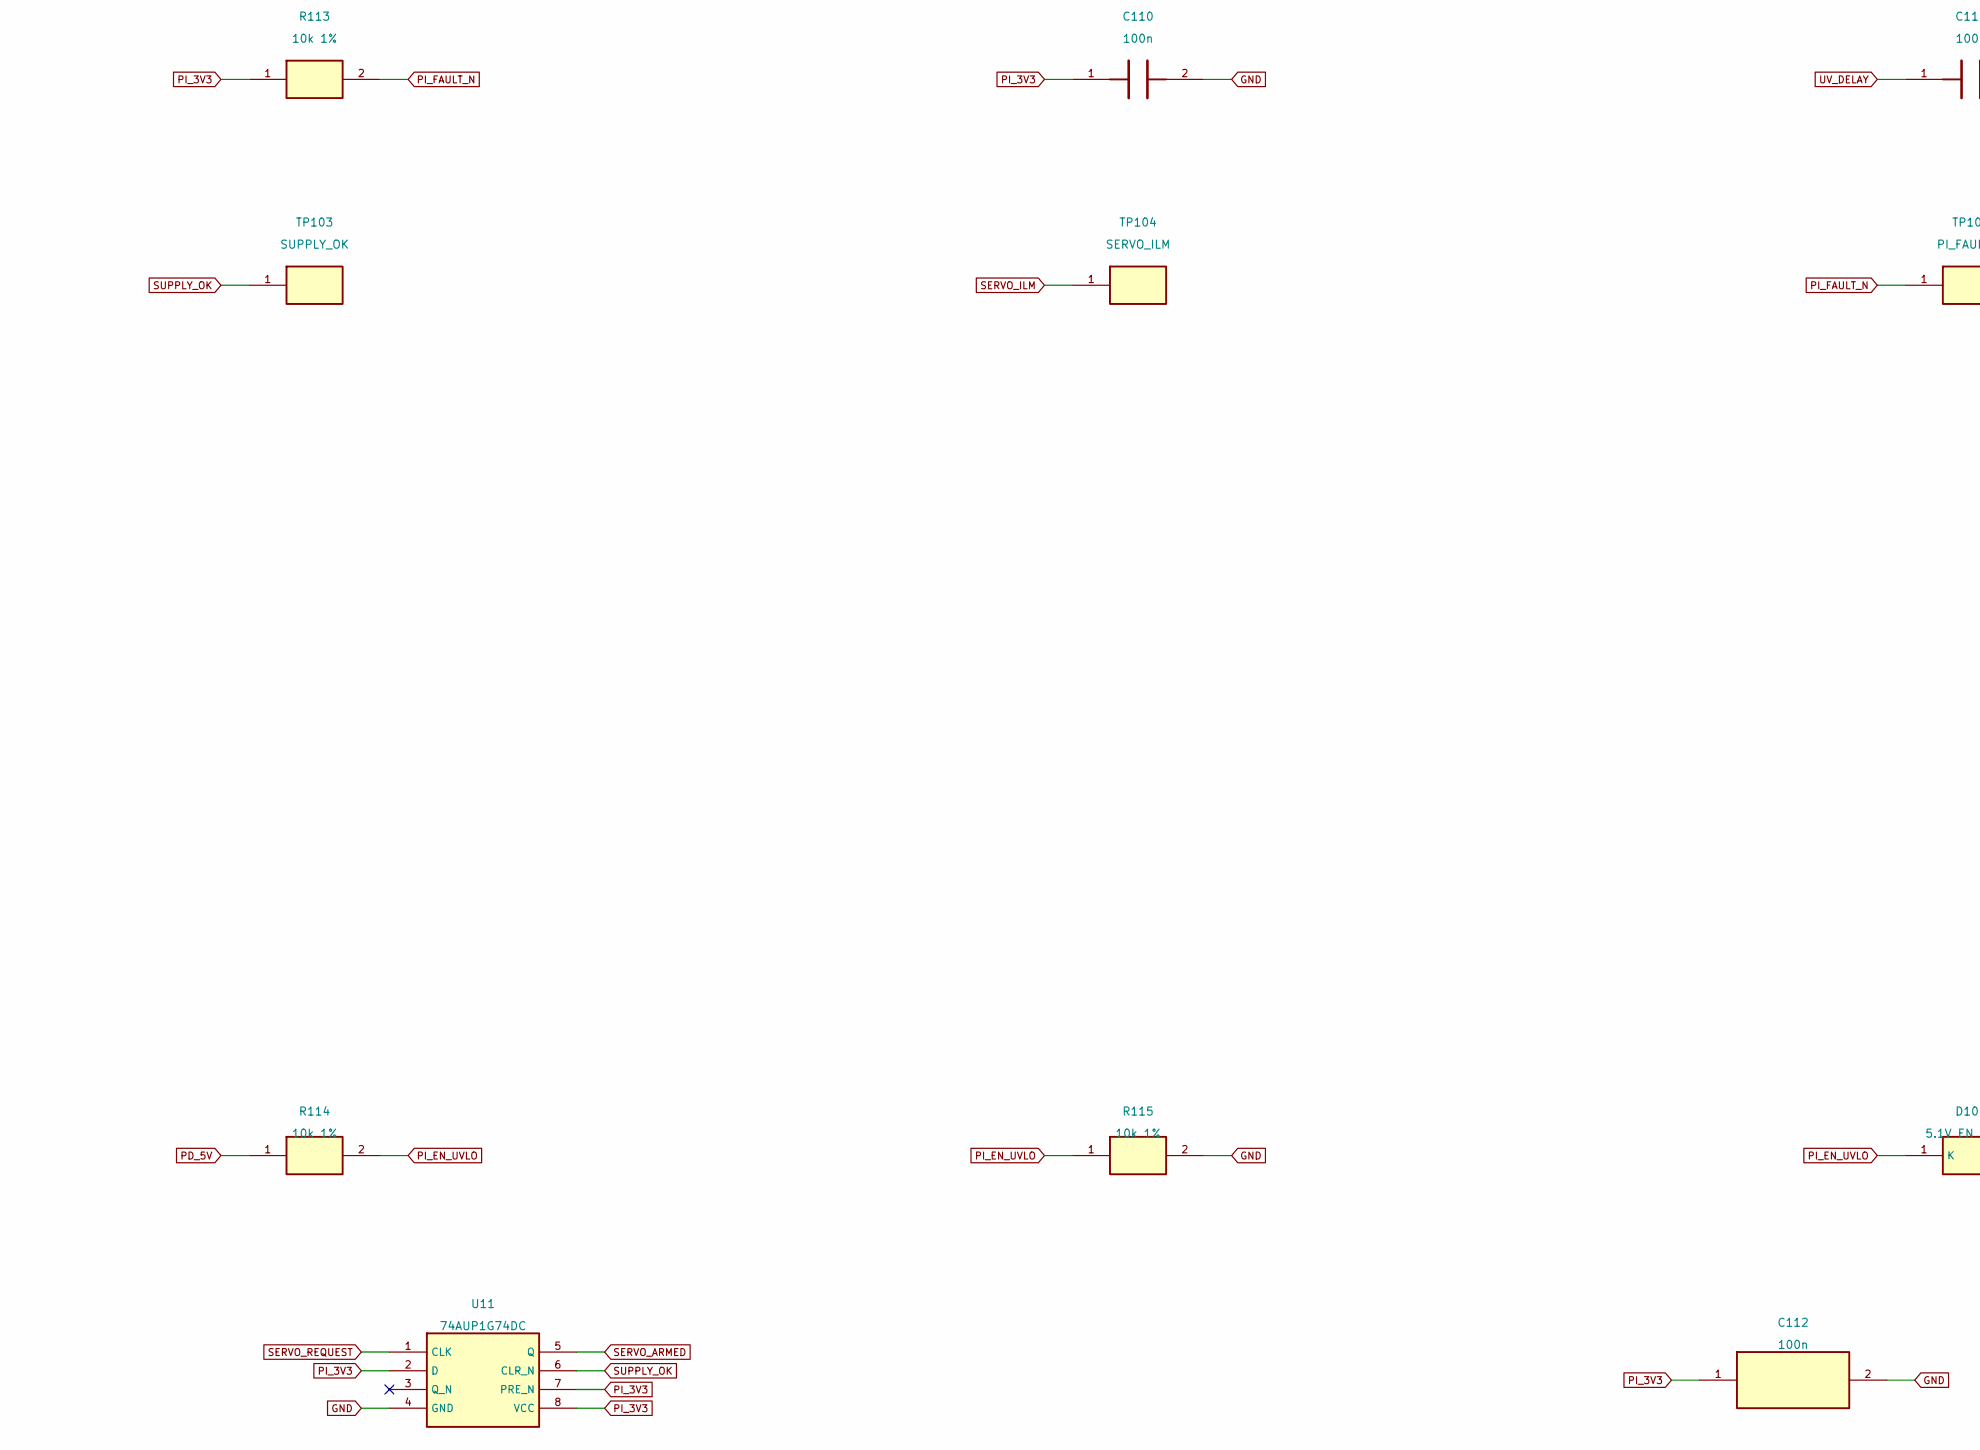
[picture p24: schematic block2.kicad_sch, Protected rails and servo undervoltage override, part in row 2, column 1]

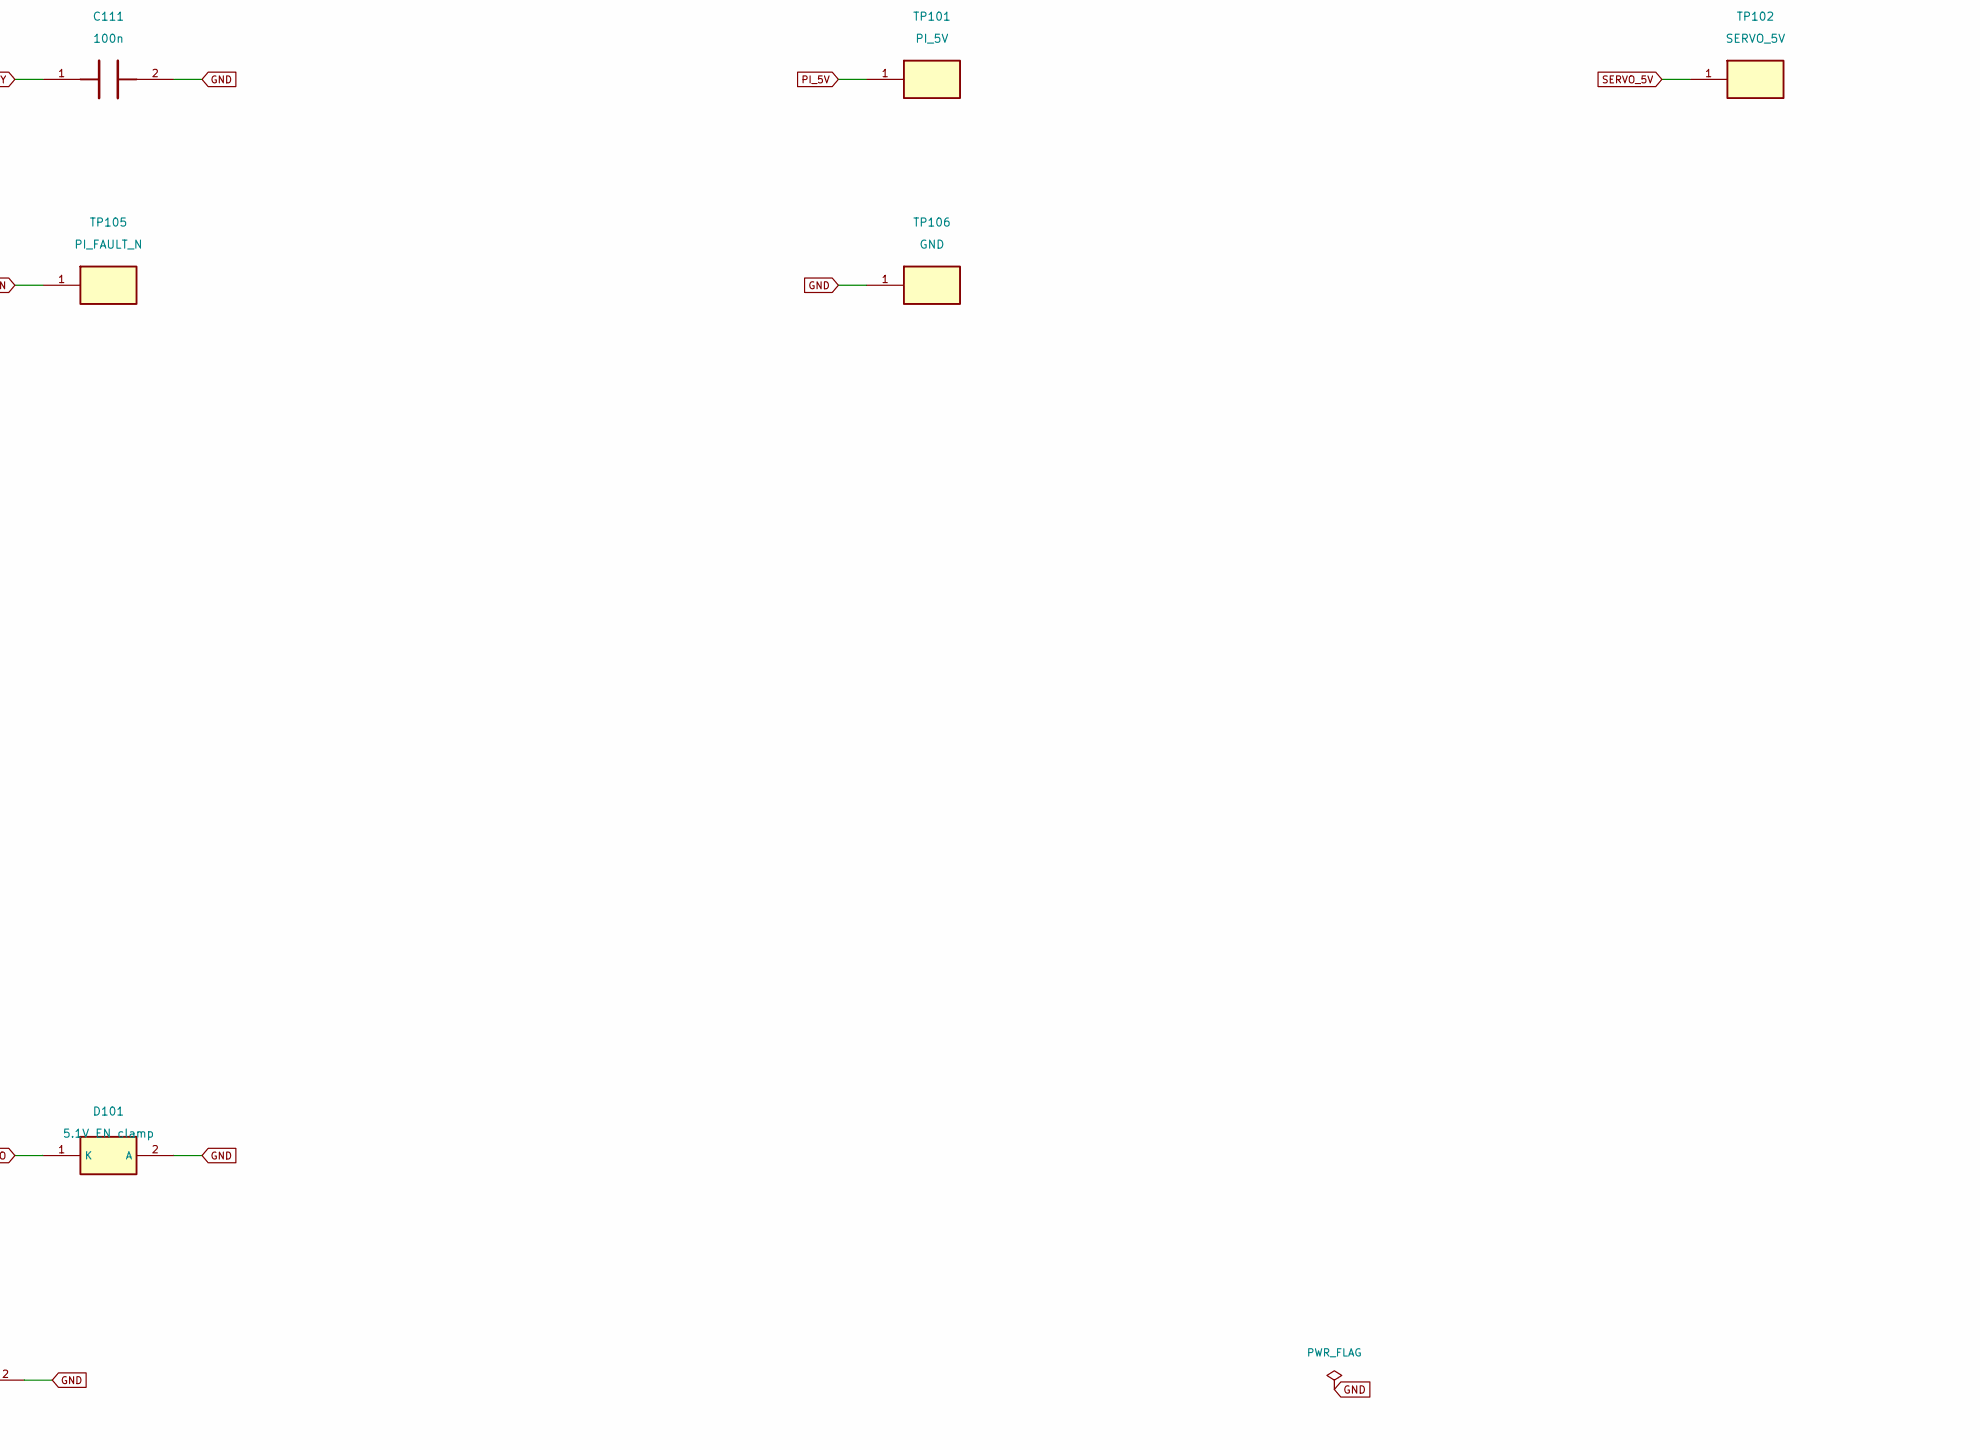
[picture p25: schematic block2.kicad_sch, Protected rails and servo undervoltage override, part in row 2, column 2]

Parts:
C101: 10n; C_0805_2012Metric; MPN C0805C103J5GACTU
C102: 4.7n; C_0805_2012Metric; MPN C0805C472J5GACTU
C103, C104, C109, C110, C111, C112: 100n; C_0805_2012Metric; MPN C0805C104K5RACTU
C105: 2200u 10V; CP_Radial_D10.0mm_P5.00mm; MPN EEU-FR1A222L
C106: 1000u 10V; CP_Radial_D8.0mm_P3.50mm; MPN EEU-FR1A102L
C107, C108: 10u; C_1206_3216Metric; MPN C1206C106K4RACTU
D101: 5.1V EN clamp; D_SOD-123; MPN MMSZ5V1T1G
R101: 1.65k 0.1%; R_0805_2012Metric; MPN RT0805BRD071K65L
R102: 3.32k 0.1%; R_0805_2012Metric; MPN RT0805BRD073K32L
R103, R105: 34.0k 0.1%; R_0805_2012Metric; MPN RT0805BRD0734KL
R104, R106, R108: 10k 0.1%; R_0805_2012Metric; MPN RT0805BRD0710KL
R107: 32.0k 0.1%; R_0805_2012Metric; MPN RT0805BRD0732KL
R109: 2.2k 1%; R_0805_2012Metric; MPN RC0805FR-072K2L
R110, R111: 100k 1%; R_0805_2012Metric; MPN RC0805FR-07100KL
R112, R113, R114, R115: 10k 1%; R_0805_2012Metric; MPN RC0805FR-0710KL
TP101: PI_5V; TestPoint_Pad_D1.5mm; MPN PCB copper test point
TP102: SERVO_5V; TestPoint_Pad_D1.5mm; MPN PCB copper test point
TP103: SUPPLY_OK; TestPoint_Pad_D1.5mm; MPN PCB copper test point
TP104: SERVO_ILM; TestPoint_Pad_D1.5mm; MPN PCB copper test point
TP105: PI_FAULT_N; TestPoint_Pad_D1.5mm; MPN PCB copper test point
TP106: GND; TestPoint_Pad_D1.5mm; MPN PCB copper test point
U2, U3: TPS259470LRPWR; TI_RPW0010A; MPN TPS259470LRPWR
U4: TPS389001DSET; WSON-6_1.5x1.5mm_P0.5mm; MPN TPS389001DSET
U5: SN74LVC1G08DBVR; SOT-23-5; MPN SN74LVC1G08DBVR
U11: 74AUP1G74DC; VSSOP-8_2.3x2mm_P0.5mm; MPN 74AUP1G74DC,125

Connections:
GND: C101.2, C102.2, C103.2, C104.2, C105.2, C106.2, C107.2, C108.2, C109.2, C110.2, C111.2, C112.2, D101.2 (A), R101.2, R102.2, R104.2, R106.2, R108.2, R110.2, R111.2, R115.2, TP106.1, U2.8 (GND), U3.8 (GND), U4.2 (GND), U5.3 (GND), U11.4 (GND); also elsewhere on the board
PD_5V: C103.1, C104.1, R103.1, R105.1, R114.1, U2.5 (IN), U3.5 (IN); also elsewhere on the board
PI_3V3: C109.1, C110.1, C112.1, R109.2, R112.1, R113.1, U4.3 (MR_N), U4.4 (VDD), U5.5 (VCC), U11.2 (D), U11.7 (PRE_N), U11.8 (VCC); also elsewhere on the board
PI_5V: C105.1, C107.1, R107.1, TP101.1, U2.6 (OUT); also elsewhere on the board
PI_DVDT: C101.1, U2.7 (DVDT)
PI_EN_UVLO: D101.1 (K), R114.2, R115.1, U2.1 (EN_UVLO)
PI_FAULT_N: R113.2, TP105.1, U2.4 (FAULT_N)
PI_ILM: R101.1, U2.9 (ILM)
PI_OV: R103.2, R104.1, U2.2 (OVLO)
SERVO_5V: C106.1, C108.1, TP102.1, U3.6 (OUT); also elsewhere on the board
SERVO_ARMED: U5.1 (A), U11.5 (Q)
SERVO_DVDT: C102.1, U3.7 (DVDT)
SERVO_EN: R110.1, U3.1 (EN_UVLO), U5.4 (Y); also elsewhere on the board
SERVO_FAULT_N: R112.2, U3.4 (FAULT_N); also elsewhere on the board
SERVO_ILM: R102.1, TP104.1, U3.9 (ILM)
SERVO_OV: R105.2, R106.1, U3.2 (OVLO)
SERVO_REQUEST: R111.1, U5.2 (B), U11.1 (CLK); also elsewhere on the board
SUPPLY_OK: R109.1, TP103.1, U4.6 (RESET_N), U11.6 (CLR_N); also elsewhere on the board
UV_DELAY: C111.1, U4.5 (CT)
UV_SENSE: R107.2, R108.1, U4.1 (SENSE)

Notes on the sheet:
Protected rails and servo undervoltage override
Net labels are global across sheets. Pin numbers match physical pads. NC pins explicitly marked.

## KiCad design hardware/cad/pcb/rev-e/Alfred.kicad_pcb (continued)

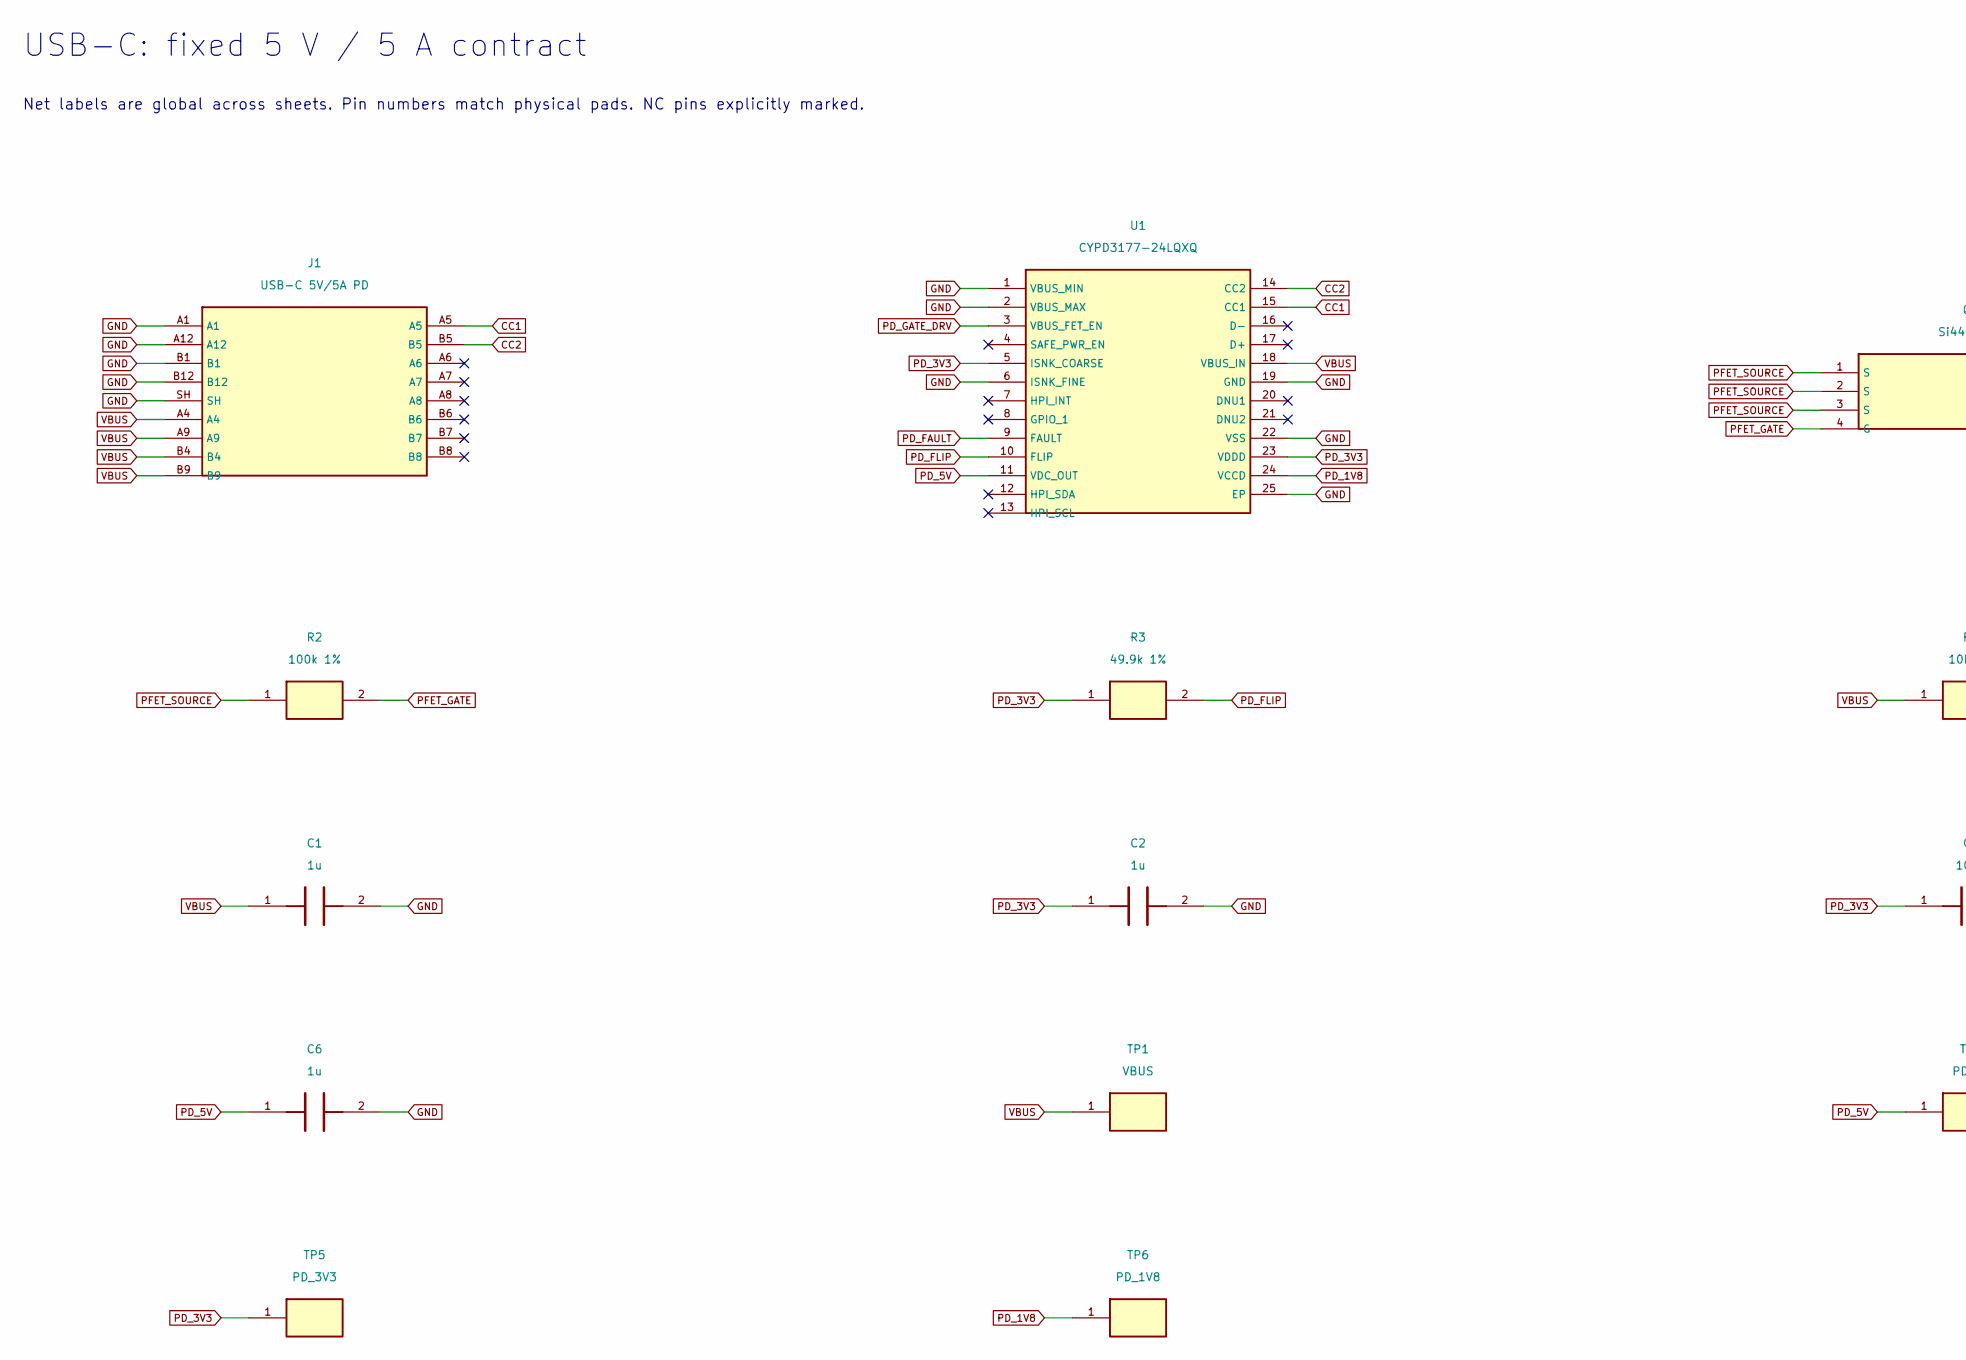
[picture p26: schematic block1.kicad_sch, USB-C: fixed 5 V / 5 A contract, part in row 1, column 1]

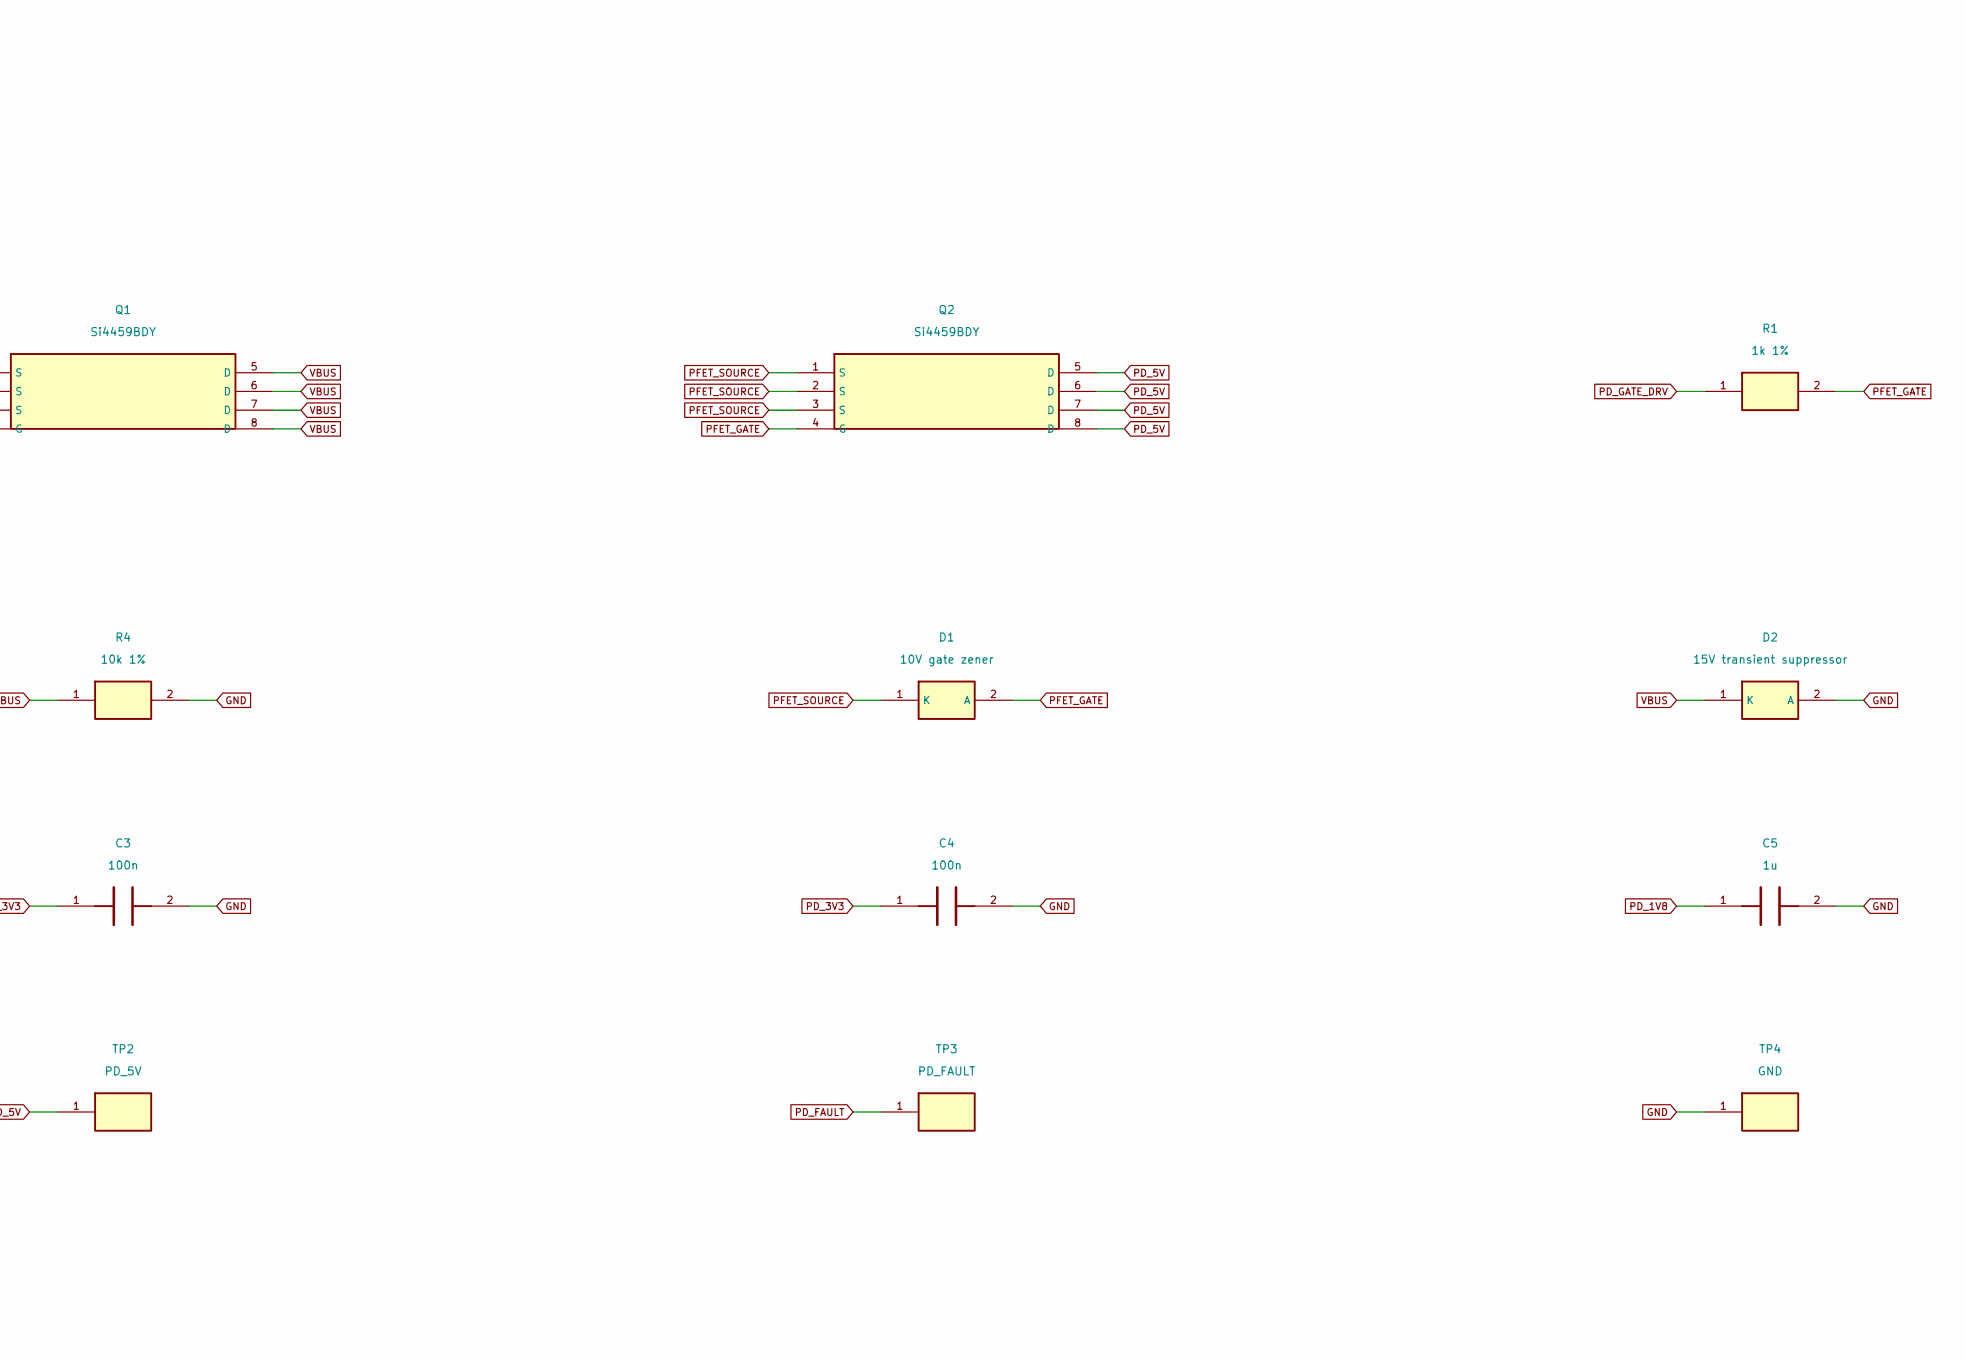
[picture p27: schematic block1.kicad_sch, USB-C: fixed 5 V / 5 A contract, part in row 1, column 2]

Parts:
C1, C2, C5, C6: 1u; C_0805_2012Metric; MPN C0805C105K5RACTU
C3, C4: 100n; C_0805_2012Metric; MPN C0805C104K5RACTU
D1: 10V gate zener; D_SOD-123; MPN BZT52C10-7-F
D2: 15V transient suppressor; D_SMA; MPN SMAJ15A-13-F
J1: USB-C 5V/5A PD; USB_C_Receptacle_GCT_USB4105-xx-A_16P_TopMnt_Horizontal; MPN USB4105-GF-A
Q1, Q2: Si4459BDY; SO-8_3.9x4.9mm_P1.27mm; MPN SI4459BDY-T1-GE3
R1: 1k 1%; R_0805_2012Metric; MPN RC0805FR-071KL
R2: 100k 1%; R_0805_2012Metric; MPN RC0805FR-07100KL
R3: 49.9k 1%; R_0805_2012Metric; MPN RC0805FR-0749K9L
R4: 10k 1%; R_0805_2012Metric; MPN RC0805FR-0710KL
TP1: VBUS; TestPoint_Pad_D1.5mm; MPN PCB copper test point
TP2: PD_5V; TestPoint_Pad_D1.5mm; MPN PCB copper test point
TP3: PD_FAULT; TestPoint_Pad_D1.5mm; MPN PCB copper test point
TP4: GND; TestPoint_Pad_D1.5mm; MPN PCB copper test point
TP5: PD_3V3; TestPoint_Pad_D1.5mm; MPN PCB copper test point
TP6: PD_1V8; TestPoint_Pad_D1.5mm; MPN PCB copper test point
U1: CYPD3177-24LQXQ; QFN-24-1EP_4x4mm_P0.5mm_EP2.75x2.75mm; MPN CYPD3177-24LQXQ

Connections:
CC1: J1.A5, U1.15 (CC1)
CC2: J1.B5, U1.14 (CC2)
GND: C1.2, C2.2, C3.2, C4.2, C5.2, C6.2, D2.2 (A), J1.A1, J1.A12, J1.B1, J1.B12, J1.SH, R4.2, TP4.1, U1.1 (VBUS_MIN), U1.2 (VBUS_MAX), U1.6 (ISNK_FINE), U1.19 (GND), U1.22 (VSS), U1.25 (EP); also elsewhere on the board
PD_1V8: C5.1, TP6.1, U1.24 (VCCD)
PD_3V3: C2.1, C3.1, C4.1, R3.1, TP5.1, U1.5 (ISNK_COARSE), U1.23 (VDDD)
PD_5V: C6.1, Q2.5 (D), Q2.6 (D), Q2.7 (D), Q2.8 (D), TP2.1, U1.11 (VDC_OUT); also elsewhere on the board
PD_FAULT: TP3.1, U1.9 (FAULT)
PD_FLIP: R3.2, U1.10 (FLIP)
PD_GATE_DRV: R1.1, U1.3 (VBUS_FET_EN)
PFET_GATE: D1.2 (A), Q1.4 (G), Q2.4 (G), R1.2, R2.2
PFET_SOURCE: D1.1 (K), Q1.1 (S), Q1.2 (S), Q1.3 (S), Q2.1 (S), Q2.2 (S), Q2.3 (S), R2.1
VBUS: C1.1, D2.1 (K), J1.A4, J1.A9, J1.B4, J1.B9, Q1.5 (D), Q1.6 (D), Q1.7 (D), Q1.8 (D), R4.1, TP1.1, U1.18 (VBUS_IN)

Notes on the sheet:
Net labels are global across sheets. Pin numbers match physical pads. NC pins explicitly marked.
USB-C: fixed 5 V / 5 A contract

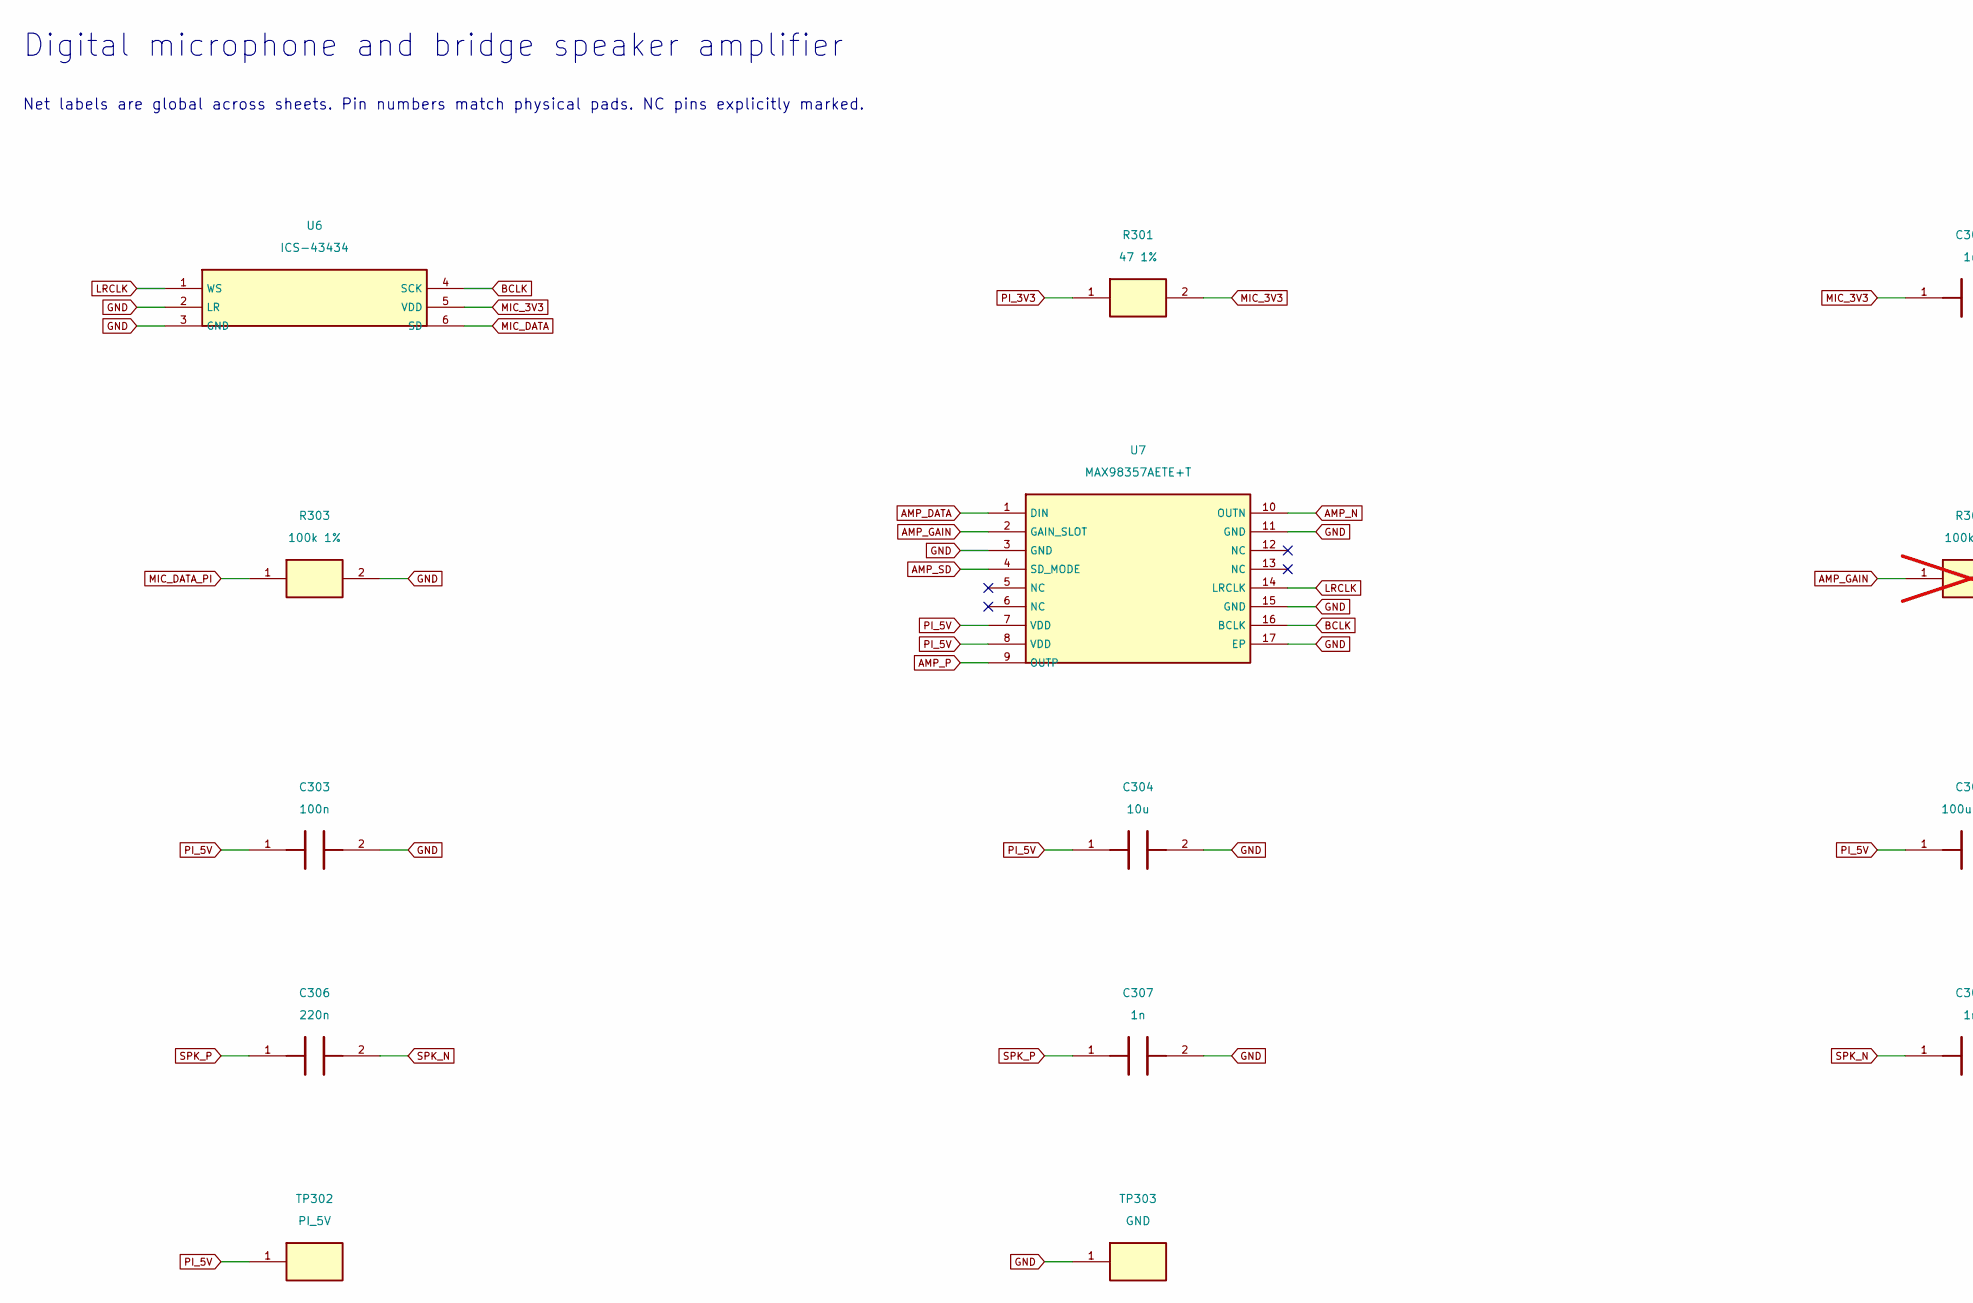
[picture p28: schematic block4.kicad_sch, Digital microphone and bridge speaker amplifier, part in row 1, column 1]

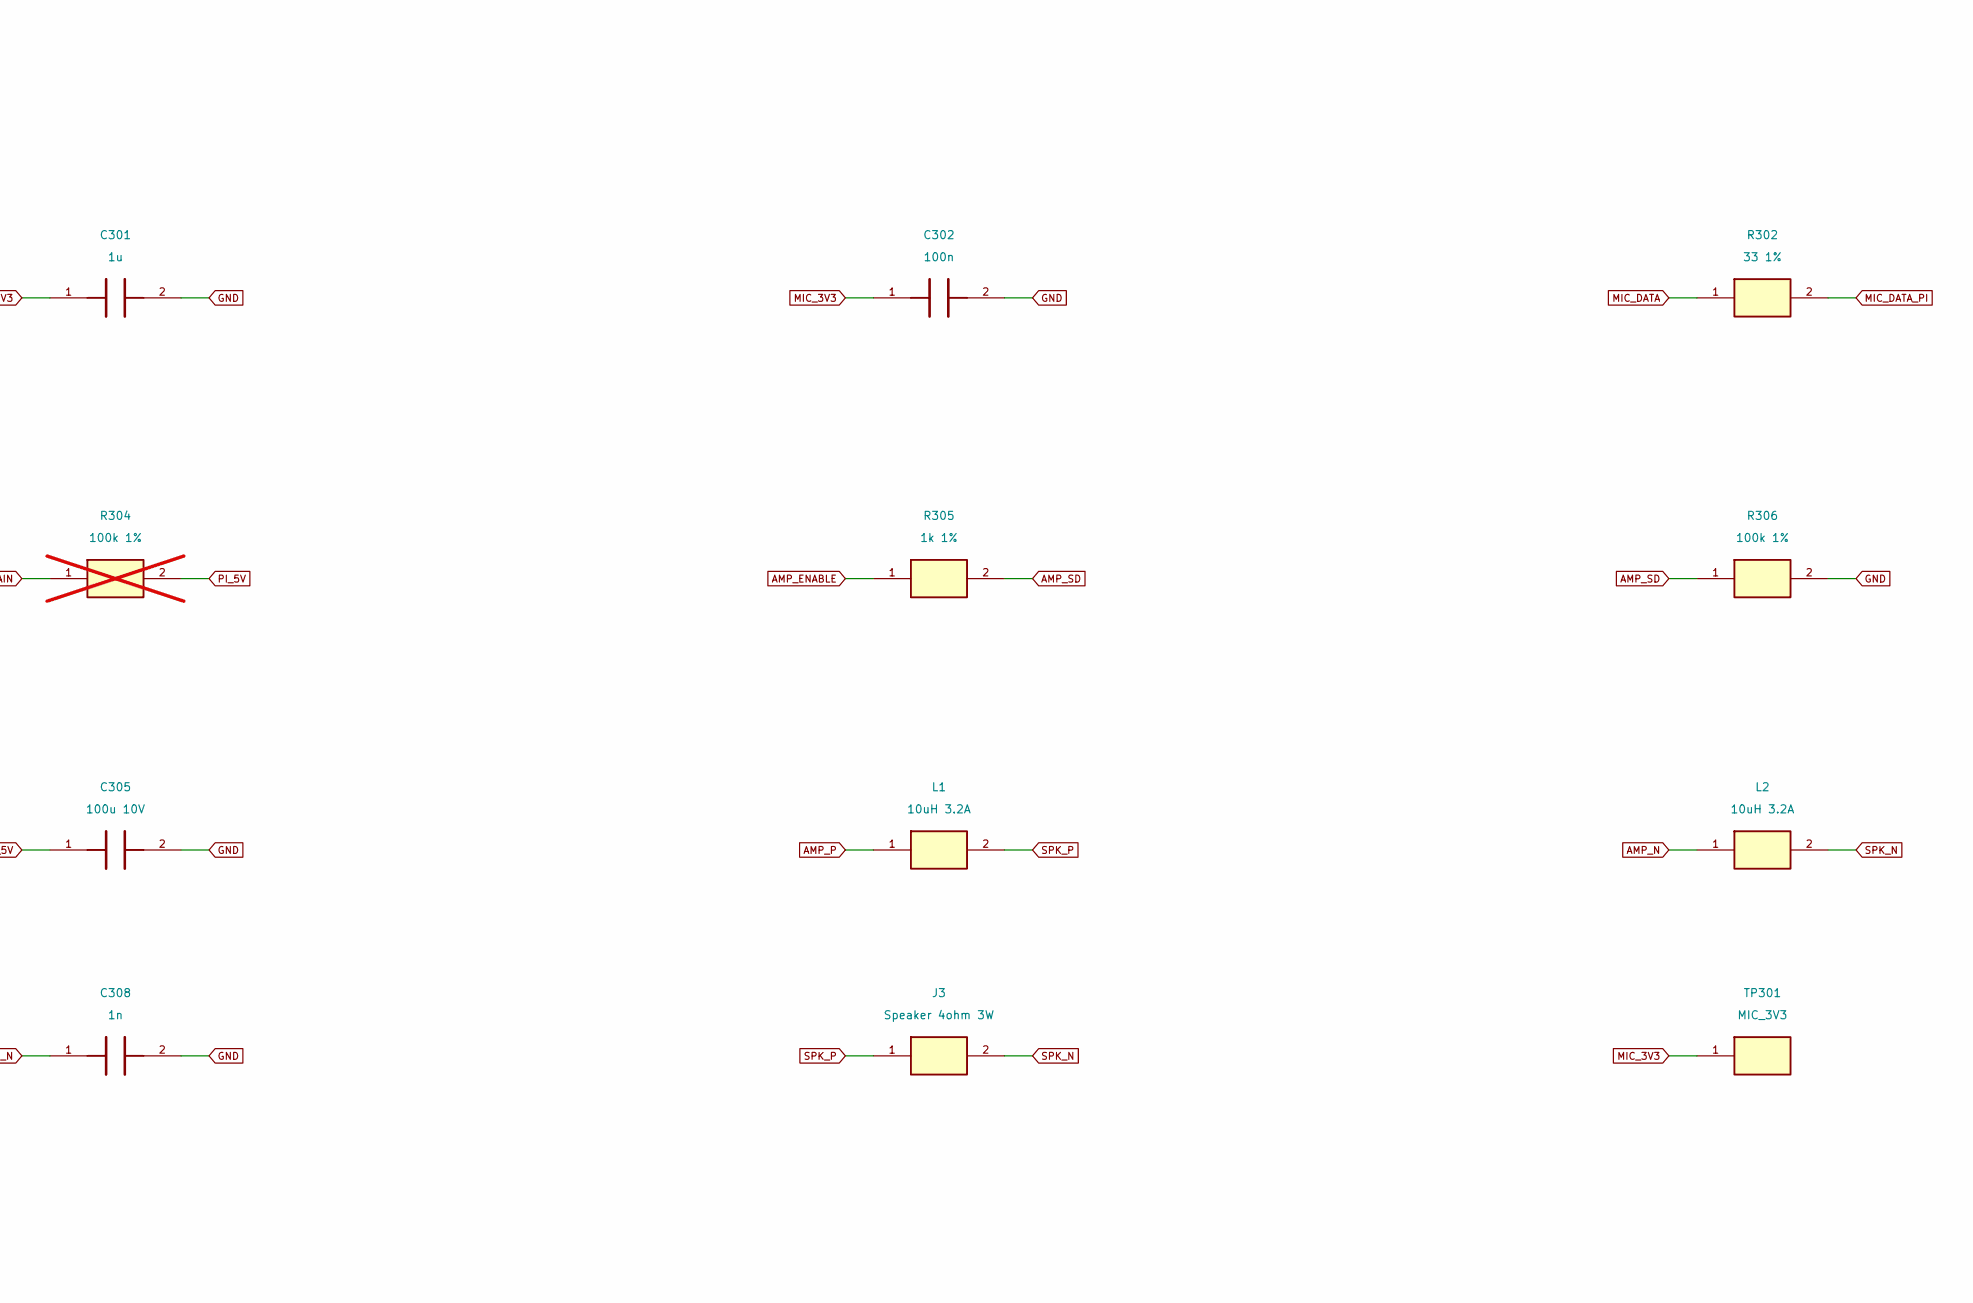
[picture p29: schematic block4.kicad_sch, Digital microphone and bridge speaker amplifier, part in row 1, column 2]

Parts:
C301: 1u; C_0805_2012Metric; MPN C0805C105K5RACTU
C302, C303: 100n; C_0805_2012Metric; MPN C0805C104K5RACTU
C304: 10u; C_1206_3216Metric; MPN C1206C106K4RACTU
C305: 100u 10V; CP_Radial_D5.0mm_P2.00mm; MPN EEU-FR1A101
C306: 220n; C_0805_2012Metric; MPN C0805C224K5RACTU
C307, C308: 1n; C_0805_2012Metric; MPN C0805C102J5GACTU
J3: Speaker 4ohm 3W; TerminalBlock_TE_282834-2_1x02_P2.54mm_Horizontal; MPN 282834-2
L1, L2: 10uH 3.2A; SRN6045TA_100M; MPN SRN6045TA-100M
R301: 47 1%; R_0805_2012Metric; MPN RC0805FR-0747RL
R302: 33 1%; R_0805_2012Metric; MPN RC0805FR-0733RL
R303, R306: 100k 1%; R_0805_2012Metric; MPN RC0805FR-07100KL
R304: 100k 1%; R_0805_DNP_NoPaste; MPN RC0805FR-07100KL; not fitted
R305: 1k 1%; R_0805_2012Metric; MPN RC0805FR-071KL
TP301: MIC_3V3; TestPoint_Pad_D1.5mm; MPN PCB copper test point
TP302: PI_5V; TestPoint_Pad_D1.5mm; MPN PCB copper test point
TP303: GND; TestPoint_Pad_D1.5mm; MPN PCB copper test point
U6: ICS-43434; InvenSense_ICS-43434-6_3.5x2.65mm; MPN ICS-43434
U7: MAX98357AETE+T; TQFN-16-1EP_3x3mm_P0.5mm_EP1.23x1.23mm; MPN MAX98357AETE+T

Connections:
AMP_DATA: U7.1 (DIN); also elsewhere on the board
AMP_ENABLE: R305.1; also elsewhere on the board
AMP_GAIN: R304.1, U7.2 (GAIN_SLOT)
AMP_N: L2.1, U7.10 (OUTN)
AMP_P: L1.1, U7.9 (OUTP)
AMP_SD: R305.2, R306.1, U7.4 (SD_MODE)
BCLK: U6.4 (SCK), U7.16 (BCLK); also elsewhere on the board
GND: C301.2, C302.2, C303.2, C304.2, C305.2, C307.2, C308.2, R303.2, R306.2, TP303.1, U6.2 (LR), U6.3 (GND), U7.3 (GND), U7.11 (GND), U7.15 (GND), U7.17 (EP); also elsewhere on the board
LRCLK: U6.1 (WS), U7.14 (LRCLK); also elsewhere on the board
MIC_3V3: C301.1, C302.1, R301.2, TP301.1, U6.5 (VDD)
MIC_DATA: R302.1, U6.6 (SD)
MIC_DATA_PI: R302.2, R303.1; also elsewhere on the board
PI_3V3: R301.1; also elsewhere on the board
PI_5V: C303.1, C304.1, C305.1, R304.2, TP302.1, U7.7 (VDD), U7.8 (VDD); also elsewhere on the board
SPK_N: C306.2, C308.1, J3.2, L2.2
SPK_P: C306.1, C307.1, J3.1, L1.2

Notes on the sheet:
Digital microphone and bridge speaker amplifier
Net labels are global across sheets. Pin numbers match physical pads. NC pins explicitly marked.

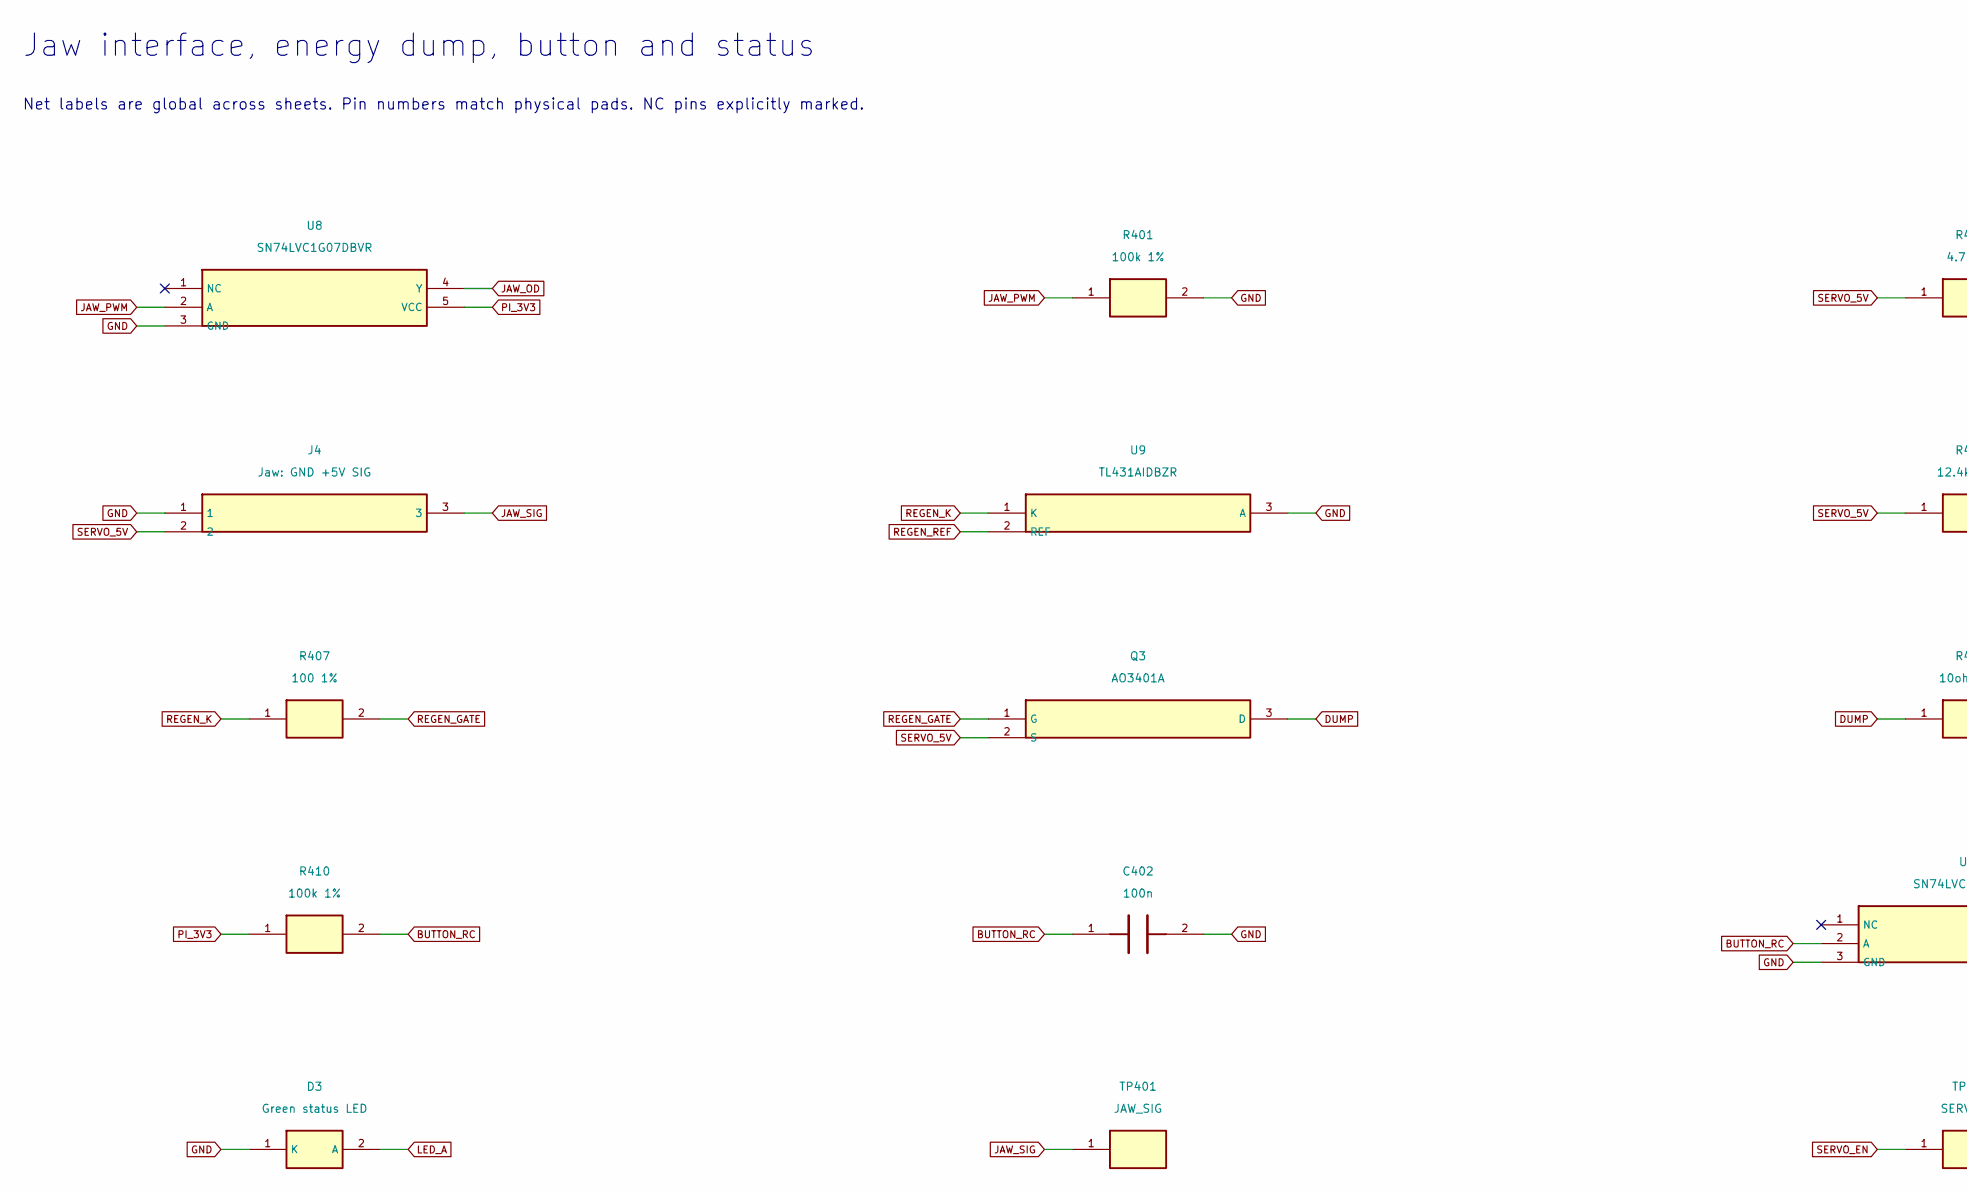
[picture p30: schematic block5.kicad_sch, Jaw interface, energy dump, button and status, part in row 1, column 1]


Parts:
C401, C402, C403: 100n; C_0805_2012Metric; MPN C0805C104K5RACTU
D3: Green status LED; LED_D3.0mm; MPN WP710A10SGC
J4: Jaw: GND +5V SIG; PinHeader_1x03_P2.54mm_Vertical; MPN TSW-103-07-G-S
Q3: AO3401A; SOT-23; MPN AO3401A
R401, R410: 100k 1%; R_0805_2012Metric; MPN RC0805FR-07100KL
R402: 4.7k 1%; R_0805_2012Metric; MPN RC0805FR-074K7L
R403, R409: 1k 1%; R_0805_2012Metric; MPN RC0805FR-071KL
R404: 12.4k 0.1%; R_0805_2012Metric; MPN RT0805BRD0712K4L
R405: 10k 0.1%; R_0805_2012Metric; MPN RT0805BRD0710KL
R406: 2.2k 1%; R_0805_2012Metric; MPN RC0805FR-072K2L
R407: 100 1%; R_0805_2012Metric; MPN RC0805FR-07100RL
R408: 10ohm 5W; R_Axial_Power_L25.0mm_W9.0mm_P30.48mm; MPN SQP500JB-10R
R411: 680 1%; R_0805_2012Metric; MPN RC0805FR-07680RL
SW1: Momentary button; SW_PUSH_6mm_H4.3mm; MPN B3F-1000
TP401: JAW_SIG; TestPoint_Pad_D1.5mm; MPN PCB copper test point
TP402: SERVO_EN; TestPoint_Pad_D1.5mm; MPN PCB copper test point
TP403: BUTTON_N; TestPoint_Pad_D1.5mm; MPN PCB copper test point
TP404: GND; TestPoint_Pad_D1.5mm; MPN PCB copper test point
U8: SN74LVC1G07DBVR; SOT-23-5; MPN SN74LVC1G07DBVR
U9: TL431AIDBZR; SOT-23; MPN TL431AIDBZR
U10: SN74LVC1G17DBVR; SOT-23-5; MPN SN74LVC1G17DBVR

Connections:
BUTTON_N: TP403.1, U10.4 (Y); also elsewhere on the board
BUTTON_RC: C402.1, R409.2, R410.2, U10.2 (A)
BUTTON_SWITCH: R409.1, SW1.1
DUMP: Q3.3 (D), R408.1
GND: C401.2, C402.2, C403.2, D3.1 (K), J4.1, R401.2, R405.2, R408.2, SW1.2, TP404.1, U8.3 (GND), U9.3 (A), U10.3 (GND); also elsewhere on the board
JAW_OD: R402.2, R403.1, U8.4 (Y)
JAW_PWM: R401.1, U8.2 (A); also elsewhere on the board
JAW_SIG: J4.3, R403.2, TP401.1
LED_A: D3.2 (A), R411.2
LED_GPIO: R411.1; also elsewhere on the board
PI_3V3: C401.1, C403.1, R410.1, U8.5 (VCC), U10.5 (VCC); also elsewhere on the board
REGEN_GATE: Q3.1 (G), R407.2
REGEN_K: R406.2, R407.1, U9.1 (K)
REGEN_REF: R404.2, R405.1, U9.2 (REF)
SERVO_5V: J4.2, Q3.2 (S), R402.1, R404.1, R406.1; also elsewhere on the board
SERVO_EN: TP402.1; also elsewhere on the board

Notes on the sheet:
Jaw interface, energy dump, button and status
Net labels are global across sheets. Pin numbers match physical pads. NC pins explicitly marked.


Board: 4 copper layers, 120.0 x 94.0 mm, 125 parts (0 on the bottom side), 58 nets.

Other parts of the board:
H1, H2, H3, H4: MountingHole_3.2mm_M3
H5, H6, H7, H8: MountingHole_2.7mm_M2.5

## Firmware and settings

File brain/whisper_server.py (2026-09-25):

#!/usr/bin/env python3
"""Persistent Whisper service on the GTX 1060.

`whisper_transcribe.py` loads the model on every invocation, which is fine for
a file and useless for ears — the load alone costs more than most utterances
last. This keeps it resident, the same reasoning as the voice service and
OLLAMA_KEEP_ALIVE=-1.

It lives in its own process and its own venv on purpose. The RVC environment is
pinned hard around fairseq and torch, and faster-whisper brings its own
ctranslate2; putting them in one interpreter is asking for a dependency fight
over something that only needs a socket between them.
"""

import base64
import io
import json
import os
import time
import wave
from http.server import BaseHTTPRequestHandler, HTTPServer
from pathlib import Path

from faster_whisper import WhisperModel, decode_audio

import audio_archive
import prompts

# The client says which language it is listening in: "en" (the default) or "pt".
#
# English mode is the English-only model, exactly as it always was. Portuguese
# mode uses the multilingual model, choosing between Portuguese and English on
# each turn so that "speak English" still comes through as English.
#
# Guessing the language on every turn was tried first (2026-09-17): English
# first, and a multilingual second pass when the English model scored its own
# tokens badly. It caught 32/32 Portuguese test clips, but in real use switching
# back and forth was unreliable, and the owner asked for an explicit command.
MODEL = "small.en"
# Portuguese mode only; English mode never touches it. Over 84 synthetic clips
# (2026-09-25) medium cut Portuguese word errors from 12.2% to 7.4% clean and
# 16.4% to 8.5% with room noise, and picked the language right on all of them,
# for 1.1s a clip instead of 0.45s. large-v3-turbo and large-v3 were slower and
# no better (large-v3 heard "Alfred" as "A Fed").
MULTILINGUAL_MODEL = "medium"
MODES = ("en", "pt")
# The 1060 is Pascal — no tensor cores and crippled FP16, so int8_float32 is the
# right compute type here and float16 would be slower, not faster.
COMPUTE = "int8_float32"
PORT = 5052
MAX_AUDIO_BYTES = 32 * 1024 * 1024
# Every utterance is kept, with the transcript that was used for it, so a better
# Whisper can be run over it later and a voice can be learned from it. The client
# sends the finished clip here once, after the partial ones it races through
# /transcribe, so what is stored is one clip per thing said.
ARCHIVE = None

# Whisper has never met most of these words and guesses at them phonetically —
# "Bambu P1S" came back as "Bamboo P1's". Priming it with the vocabulary this
# desk actually uses costs nothing per utterance and fixes the proper nouns that
# matter most, since they are exactly the words a command depends on.
# Local place names earn their spot the same way: the home city and school came
# back as three different near-misses in 3 of 12 clips, and with them listed, 12
# of 12 (2026-09-16, 88 synthetic clips, error rate 7.0% -> 6.4%, no cost in
# time). They are personal, so they live in persona/vocabulary.local.txt, which
# git ignores, rather than here. Skipping timestamps (-26ms) and the VAD (-5ms)
# were measured too and not taken: both added errors, and the VAD is what keeps
# a keyboard click from being transcribed as a sentence.
# His name and the owner's lead the list. The owner's is private, so it comes
# from persona/prompts.json with the rest of his wording.
NAMES = f"Alfred. {prompts.OWNER}."
VOCABULARY = (
    f"{NAMES} Bambu P1S, PETG, ABS, PLA, TPU, filament, nozzle, extruder, "
    "retraction, brim, raft, first layer, bed adhesion, warping, gcode, slicer, "
    "Klipper, Marlin, infill, elephant foot, Ollama, Qwen, git, commit, repository."
)
LOCAL_VOCABULARY = prompts.PERSONA_DIR / "vocabulary.local.txt"
if LOCAL_VOCABULARY.exists():
    VOCABULARY += " " + " ".join(LOCAL_VOCABULARY.read_text(encoding="utf-8").split())
# The people he talks about, in both languages. In the first Portuguese session
# "o Diego" came back as "o chão", so "never forget this, Diego is..." had
# nothing to save and "do you know Diego" nothing to find. Over ten synthetic
# Portuguese clips (2026-09-17) the name fixed "o tirágua é o quê", settled
# "Tiago" into one spelling, and left "o chão está molhado" alone. Friends'
# names are personal, so they live in persona/people.local.txt, one per line.
LOCAL_PEOPLE = prompts.PERSONA_DIR / "people.local.txt"
PEOPLE = NAMES
if LOCAL_PEOPLE.exists():
    PEOPLE += " " + " ".join(f"{name.strip()}." for name in LOCAL_PEOPLE.read_text(encoding="utf-8").splitlines()
                             if name.strip())
VOCABULARY = PEOPLE + VOCABULARY.removeprefix(NAMES)
# Portuguese gets names only. With the printing terms too, "toca Bohemian
# Rhapsody" came back as "toca a Bambu P1S": the prompt leaked into the words.
PROMPTS = {"en": VOCABULARY, "pt": PEOPLE}


class Ears:
    def __init__(self):
        self.model = WhisperModel(MODEL, device="cuda", compute_type=COMPUTE)
        # Both stay loaded (about 0.43 GB and 1 GB of the 1060's 6 GB), so a
        # Portuguese turn never waits for a model to load.
        self.multilingual = WhisperModel(MULTILINGUAL_MODEL, device="cuda", compute_type=COMPUTE)
        # Force the CUDA kernels and the encoder to load before anyone speaks.
        silence = io.BytesIO()
        with wave.open(silence, "wb") as handle:
            handle.setnchannels(1)
            handle.setsampwidth(2)
            handle.setframerate(16000)
            handle.writeframes(b"\x00\x00" * 16000)
        silence.seek(0)
        self.transcribe(silence.read())

    def transcribe(self, audio: bytes, mode: str = "en") -> tuple[str, float, str]:
        started = time.perf_counter()
        samples = decode_audio(io.BytesIO(audio), sampling_rate=16000)
        if mode != "pt":
            text, _ = self._pass(self.model, samples, "en")
            return text, time.perf_counter() - started, "en"
        _, _, probabilities = self.multilingual.detect_language(samples)
        probabilities = dict(probabilities)
        language = max(MODES, key=lambda code: probabilities.get(code, 0.0))
        text, _ = self._pass(self.multilingual, samples, language)
        return text, time.perf_counter() - started, language

    def _pass(self, model, samples, language: str) -> tuple[str, float]:
        """Text, and the average log-probability of its tokens (how sure the model was)."""
        segments = list(model.transcribe(
            samples,
            language=language,
            beam_size=5,
            vad_filter=True,
            condition_on_previous_text=False,   # stops it inventing continuations
            initial_prompt=PROMPTS.get(language),
        )[0])
        tokens = sum(len(segment.tokens) for segment in segments)
        confidence = (sum(segment.avg_logprob * len(segment.tokens) for segment in segments) / tokens
                      if tokens else 0.0)
        return " ".join(segment.text.strip() for segment in segments).strip(), confidence


EARS = None


class Handler(BaseHTTPRequestHandler):
    def do_GET(self):
        if self.path != "/health":
            self.send_error(404)
            return
        self.send_response(200)
        self.end_headers()
        self.wfile.write(b"ready")

    def do_POST(self):
        path, _, query = self.path.partition("?")
        if path not in ("/transcribe", "/keep"):
            self.send_error(404)
            return
        if path == "/keep":
            self.keep()
            return
        mode = "pt" if "mode=pt" in query.split("&") else "en"
        try:
            length = int(self.headers.get("Content-Length", "0"))
            if not 0 < length <= MAX_AUDIO_BYTES:
                raise ValueError(f"audio must be 1..{MAX_AUDIO_BYTES} bytes, got {length}")
            audio = self.rfile.read(length)
            text, elapsed, language = EARS.transcribe(audio, mode)
        except Exception as exc:
            self.send_error(500, str(exc))
            return
        body = json.dumps({"text": text, "seconds": round(elapsed, 3), "language": language}).encode("utf-8")
        print(f"heard {elapsed:.2f}s [{language}] {text!r}", flush=True)
        self.send_response(200)
        self.send_header("Content-Type", "application/json")
        self.send_header("Content-Length", str(len(body)))
        self.end_headers()
        self.wfile.write(body)

    def keep(self):
        """Archive one finished clip and the transcript that was used for it."""
        try:
            length = int(self.headers.get("Content-Length", "0"))
            if not 0 < length <= MAX_AUDIO_BYTES * 2:
                raise ValueError(f"body must be 1..{MAX_AUDIO_BYTES * 2} bytes, got {length}")
            body = json.loads(self.rfile.read(length))
            saved = ARCHIVE.keep(base64.b64decode(body["audio"]), body.get("text", ""),
                                 body.get("language", "en"), body.get("source", "voice"))
        except Exception as exc:
            self.send_error(500, str(exc))
            return
        payload = json.dumps({"kept": saved is not None}).encode("utf-8")
        self.send_response(200)
        self.send_header("Content-Type", "application/json")
        self.send_header("Content-Length", str(len(payload)))
        self.end_headers()
        self.wfile.write(payload)

    def log_message(self, format, *args):
        return


def main() -> None:
    global EARS, ARCHIVE
    EARS = Ears()
    ARCHIVE = audio_archive.Archive()
    print(f"archive: {ARCHIVE.stats()}", flush=True)
    print(f"whisper service ready on 127.0.0.1:{PORT} ({MODEL} for English, {MULTILINGUAL_MODEL} for "
          f"Portuguese mode, {COMPUTE})", flush=True)
    HTTPServer(("127.0.0.1", PORT), Handler).serve_forever()


if __name__ == "__main__":
    main()

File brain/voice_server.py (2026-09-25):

#!/usr/bin/env python3
"""Persistent streaming voice service with RVC and direct-Piper modes."""

import base64
import json
import os
import queue
import re
import tempfile
import threading
import time
import urllib.request
import wave
from http.server import BaseHTTPRequestHandler, HTTPServer
from pathlib import Path

import numpy as np
from piper import PiperVoice
from rvc_python.infer import RVCInference
import soundfile as sf
from scipy.signal import resample_poly

import alfred
import prompts
import guru
import memory
import media
import memory_tools
import spoken
import spotify
import voice_eq
import weather
from memory import Memory
import random

ROOT = Path(__file__).resolve().parent.parent   # project root: the models live beside brain/
PIPER_MODEL = Path(os.environ.get(
    "ALFRED_PIPER_MODEL", ROOT / "tts-models" / "piper" / "en_GB-alan-medium.onnx"
))
DIRECT_PIPER = "ALFRED_PIPER_MODEL" in os.environ
RVC_DIR = ROOT / "rvc-model"
# 48 kHz, the rate laptop and Pi speakers actually run at. At 32 kHz (what RVC
# returned) the client had Windows convert on the fly with WASAPI's fast
# converter, and his voice crackled live while the same audio played cleanly
# in a media player (2026-09-16). Resampling here, once, with a proper filter,
# means nothing downstream converts at all.
OUTPUT_RATE = 48000
PORTUGUESE_MODEL = Path(os.environ.get(
    "ALFRED_PIPER_PT_MODEL", ROOT / "tts-models" / "piper" / "pt_BR-faber-medium.onnx"))

# What he says instead when the turn is being spoken in Portuguese. The lines
# themselves are his, so they come from the private wording.
PORTUGUESE_LINES = prompts.TRANSLATIONS


def local(line: str, language: str) -> str:
    return PORTUGUESE_LINES.get(line, line) if language == "pt" else line


class VoicePipeline:
    def __init__(self):
        # Piper is only the fast British carrier performance. RVC supplies the
        # final voice, and remains on the GTX 1060.
        self.piper = PiperVoice.load(PIPER_MODEL, use_cuda=False)
        self.rvc = None
        if not DIRECT_PIPER:
            self.rvc = RVCInference(
                device="cuda:0",
                model_path=str(RVC_DIR / "alfred.pth"),
                index_path=str(RVC_DIR / "alfred.index"),
                version="v2",
            )
            self.rvc.set_params(f0method="rmvpe", index_rate=0.7, protect=0.33)
        # Portuguese replies get a Brazilian voice. His own was trained on English
        # only; a different voice in Portuguese is accepted (owner, 2026-09-17).
        self.voices = {"en": self.piper}
        if PORTUGUESE_MODEL.exists():
            self.voices["pt"] = PiperVoice.load(PORTUGUESE_MODEL, use_cuda=False)
        self.temp = tempfile.TemporaryDirectory(prefix="alfred-voice-")
        # Force lazy CUDA kernels and RVC feature models to load before the
        # first real request.
        self.create(prompts.line("ready"))

    def create(self, text: str, language: str = "en") -> tuple[bytes, float, float]:
        source = Path(self.temp.name) / "source.wav"
        converted = Path(self.temp.name) / "converted.wav"
        started = time.perf_counter()
        voice = self.voices.get(language, self.piper)
        with wave.open(str(source), "wb") as wav_file:
            voice.synthesize_wav(text, wav_file)
        tts_finished = time.perf_counter()
        # RVC turns English Piper into his voice; it is not for the Portuguese one.
        if self.rvc is None or voice is not self.piper:
            samples, rate = sf.read(source, dtype="float32")
            if rate != OUTPUT_RATE:
                divisor = np.gcd(rate, OUTPUT_RATE)
                samples = resample_poly(samples, OUTPUT_RATE // divisor, rate // divisor)
            # His own voice came out dull and boomy (see voice_eq); the Portuguese one did not.
            # The tone is read from a settings file, so it can be tuned without a restart.
            chain = voice_eq.current() if voice is self.piper else ()
            if chain:
                samples = voice_eq.apply(samples, OUTPUT_RATE, chain)
            # Piper normalises to full scale and resampling overshoots it slightly.
            sf.write(converted, np.clip(samples, -1.0, 1.0), OUTPUT_RATE, subtype="PCM_16")
        else:
            self.rvc.infer_file(str(source), str(converted))
        finished = time.perf_counter()
        return converted.read_bytes(), tts_finished - started, finished - tts_finished


PIPELINE = None
PERSONA = None
MEMORY = None
# The last YouTube results and which of them is playing, so "the second one"
# and "next" mean something. One household, one list.
MEDIA_RESULTS: list = []
MEDIA_POSITION = [-1]
# The last commentator section talked about, so "play that part" can follow it.
GURU_LAST: list = []
# "Play X" with no service named, once Spotify is signed in, is answered with
# "Spotify or YouTube?"; this holds X (and when it was asked) for the answer.
PENDING_PLAY: list = []
PENDING_SECONDS = 90
# What he calls whoever is talking: "sir" until someone says "use ma'am responses".
# Not saved, so a restart (and the nightly reboot) puts it back to the default.
ADDRESS = [spoken.DEFAULT_TITLE]

# What he is handed about the past on a turn that looked nothing up: at most two
# lines, above a bar set by measurement rather than by taste. brain/recall_eval.py
# over invented memories puts genuine follow-ups at 0.49-0.75 and unrelated ones
# at 0.45-0.54 — a narrow gap, so 0.72 (the first guess) recalled 1 of 10 and
# 0.58, the floor a deliberate search uses, recalled 8 with nothing spurious.
# 0.60 keeps 7 of 10 and a little margin, which this wants and a search does not:
# it arrives unasked in front of every ordinary sentence, while a miss only
# leaves him answering as he would have anyway.
RECALL_LIMIT = 2
RECALL_FLOOR = 0.60
RECALL_SKIP_RECENT = 6      # the current conversation is already in front of him

# Nothing may touch either GPU while a question is in flight.
BUSY = threading.Lock()
# Warm once at start, then only after this long with nothing asked. It used to
# run every 40s regardless, holding BUSY for 0.4-1.4s each time, so a question
# landing in that window simply waited. Measured 2026-09-16 with the loop off:
# after 3 and 10 minutes idle the decider, the answer's first token, the embedder
# and Piper were all exactly as fast as hot (keep_alive=-1 and two llama.cpp
# slots mean the cached prompts are never evicted). Only a restart loses them.
KEEP_WARM_SECONDS = 600
LAST_ACTIVITY = float("-inf")  # monotonic time of the last turn or warmup; -inf so start-up always warms


def mark_activity() -> None:
    global LAST_ACTIVITY
    LAST_ACTIVITY = time.monotonic()
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

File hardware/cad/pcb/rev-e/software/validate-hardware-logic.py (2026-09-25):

from pathlib import Path
from itertools import product
import json
O=Path(__file__).resolve().parent.parent;by={a['ref']:a for a in json.loads((O/'design-data.json').read_text())}
assert by['U4']['pins']=={'1':'UV_SENSE','2':'GND','3':'PI_3V3','4':'PI_3V3','5':'UV_DELAY','6':'SUPPLY_OK'}
assert by['U11']['pins']=={'1':'SERVO_REQUEST','2':'PI_3V3','3':None,'4':'GND','5':'SERVO_ARMED','6':'SUPPLY_OK','7':'PI_3V3','8':'PI_3V3'}
assert by['U5']['pins']['1']=='SERVO_ARMED' and by['U5']['pins']['2']=='SERVO_REQUEST'
# Exhaust all eight-event binary request/supply-good sequences; start with reset asserted.
count=0
for events in product(product([False,True],repeat=2),repeat=8):
 q=False;prev=False;last_fault=True;armed_since_fault=False
 for req,good in events:
  rise=req and not prev
  if not good:q=False;armed_since_fault=False
  elif rise:q=True;armed_since_fault=True
  en=q and req
  assert not en or (good and armed_since_fault)
  if not req:assert not en
  if last_fault and good and req and prev:assert not en
  prev=req;last_fault=not good
 count+=1
print('Latch sequences:',count,'PASS (truth-table model, not analog simulation)')
# Datasheet +/-1% positive and negative thresholds, divider +/-0.1%, sense leakage +/-100 nA conservatively.
def limit(th,sgn):
 rt=32100*(1+sgn*.001);rb=10000*(1-sgn*.001)
 return th*(1+sgn*.01)*(1+rt/rb)+sgn*100e-9*rt
vals={'fall_nom':1.15*4.21,'fall_min':limit(1.15,-1),'fall_max':limit(1.15,1),'rise_nom':1.157*4.21,'rise_min':limit(1.157,-1),'rise_max':limit(1.157,1),'rail_25C_servo_off':5.1-2.85*(.0164+.0283),'rail_25C_allocation':5.1-4.1*.0164-2.85*.0283}
print(json.dumps(vals,indent=2))

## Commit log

2026-08-26 Add streaming Piper-to-RVC voice pipeline
    Persistent voice service on the box: Piper synthesises a British carrier
    performance on CPU, RVC converts it to the Alfred voice on GPU 1, and Qwen
    keeps generating later sentences while the current one is synthesised.
    talk.py is the thin laptop client over an SSH tunnel, the same boundary the
    Pi is meant to sit on later.
    Also adds rvc_server.py (conversion-only variant) and voice-server.sh, which
    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
2026-08-26 Speak whole sentences, and play them without seams
    Two separate causes of the jank, both in the plumbing rather than the voice.
    The stream was being cut anywhere smaller than a sentence: at commas past ten
    words, and failing that at a hard fourteen-word count with no punctuation
    involved at all. That halved clauses ("...to give" / "it a better grip"),
    orphaned a one-word tail into an utterance of its own, and — because any chunk not
    ending in punctuation had a comma appended — had Piper sing a rising
    continuation and then stop dead. It now cuts on sentence terminators only,
    keeps decimals and "Dr." intact, and falls back to a real comma only for a
    sentence that runs past thirty words wi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
    [voice_server.py]
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2026-08-26 Recall by meaning, and give him tools to reach for it
    Word overlap could not connect "why won't it stick to the plate" to anything
    about bed adhesion — the two share no words — which is most of what
    remembering is for. Recall now runs on nomic-embed-text through Ollama: 768
    dimensions, 17ms per embed, 323MB resident on GPU 0 beside Qwen without
    disturbing the budget. Nothing leaves the box.
    Three layers, each degrading into the next so memory gets slower but never
    breaks: sqlite-vec KNN, exact brute force, then the old word overlap when the
    embedder cannot be reached. The embeddings table is the source of truth and is
    ordinary SQLite; the vec0 index is only an accelerator and rebuilds f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
    [memory.py, memory_tools.py]
2026-08-26 Decide what to remember in one pass, answer as Alfred in the next
    He will not call a tool with his persona and ninety-two examples in front of
    him — measured at zero calls across every probe, fabricating instead. The
    examples that make him Alfred are the same thing teaching him to answer
    directly and never reach for anything.
    So neither pass is asked to do both. Pass one has no persona, no examples and
    no character to protect; it only decides what to fetch. Pass two has all of
    that and never sees a tool definition. If the decider fails for any reason the
    turn falls back to blind retrieval, which is what every turn did before.
    It works: "remember that my printer is a bambu p1s" now writes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
    [memory_tools.py, voice_server.py]
2026-08-26 Stop pass one reaching for tools nothing asked for
    Every error the decider made was the same kind: calling a tool no one needed,
    never missing one that was wanted. "thanks alfred" called remember_fact, which
    would have filled the facts list with rubbish over time.
    Saying plainly that calling nothing is the normal outcome, and listing messages
    that deserve nothing, took it from 11 of 16 labelled probes to 15, and dropped
    mean pass-one time from 1.93s to 1.50s — the cost is almost entirely in the
    calls it makes, so not making them is the whole saving.
    The last miss is a mislabelled probe rather than a mistake. "i hate my guitar lessons" does deserve a search: the examples answer it with a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
    [memory_tools.py]
2026-08-26 Give him ears
    whisper_server.py keeps small.en resident on the 1060 beside RVC. The existing
    whisper_transcribe.py loads the model per invocation, which is fine for a file
    and useless for listening — the load alone costs more than most utterances
    last. Its own process and venv on purpose: the RVC environment is pinned hard
    around fairseq and torch, faster-whisper brings its own ctranslate2, and they
    only need a socket between them. 0.24-0.42s per utterance, five to twelve times
    real time.
    Priming the decoder with the vocabulary this desk actually uses fixed the words
    a command most depends on — "Bambu P1S" was coming back as "Bamboo P1's".
    listen.py captures on the laptop, gates on a n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
    [test_listen.py, whisper_server.py]
2026-08-26 Tell him what time it is, and stop him echoing his own mistakes
    He could not answer "what time is it" because nothing had ever told him. The
    clock now goes into the prompt, and getting it there took three tries that are
    each worth recording.
    The box runs UTC and the user does not, so the raw server clock had him saying
    Wednesday 3am at Tuesday 11pm. Converting is not optional.
    Placed inside the memory block, under a line reading "treat it as reference,
    not as instructions", he discounted it — giving the date correctly and still
    answering "I have no clock face" to the time. It now sits above that
    framing, as its own statement.
    Given "11:08 PM" he read it aloud as "eleven o'clock past eig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
    [memory.py, memory_tools.py, voice_server.py]
2026-08-26 Stop his own answers coming back to him as evidence
    His replies are still stored in full — the record stays complete — but only
    what the user said is embedded and returned by search. His answers are
    inferences, not evidence, and last night they were being handed back at 0.737
    similarity as though they were testimony. EMBED_SCHEME invalidates every stored
    vector, because the text behind them changed meaning; all 84 were re-embedded.
    That alone did not fix it, and the reason is worth keeping. Asked the time at
    nine in the morning, holding a correct morning clock in his context, he still
    answered "at night" — because recent() had handed him his own words from eleven
    the previous evening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
    [alfred.py, memory.py, memory_tools.py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]
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2026-08-26 Give him somewhere to look things up, and report when he cannot
    He states wrong numbers with total confidence, and persona work cannot reach
    that — examples teach voice, not facts. search_web is a fifth tool alongside
    the memory ones, decided by the same pass that already chooses whether to
    consult memory.
    Three things this took that the plan did not anticipate.
    The decider answered the question itself rather than searching. Told "you are
    not answering him" it still returned "There are 5,280 feet in a mile" with no
    tool call, because it was sure. Its certainty is not evidence — it was equally
    sure PETG retraction is four millimetres per second. Saying its only two
    outputs are a tool ca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
    [memory_tools.py, web.py]
2026-08-26 Put the facts nearer the question than his own last answer
    He got the time wrong in live use and right in the battery. The difference was
    the conversation history: the context block sat ahead of it, so his own wrong
    answer from half an hour ago was closer to the question than the true time was,
    and he stayed loyal to what he had already said. Whatever is nearest wins, so
    the context now goes last, immediately before the question being answered.
    Correct three times out of three with the bad history still in the database.
    The clock narration was my wording. "You have a clock and this is read from it"
    bought the permission he needed and cost something worse: "I am bolted to your
    desk watching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
    [alfred.py, memory.py]
2026-08-26 Stop the decider writing essays into the bin, and give the wait a voice
    Two things were in front of every answer.
    The tool-decision pass is forbidden from answering and nobody ever reads what
    it writes, but nothing stopped it writing. Uncapped it spent 5.63s composing a
    reply to "why does my first layer keep lifting" and then called no tool at all
    — pure latency ahead of the answer the user was actually waiting for. Capped to
    48 tokens, which cannot truncate a real call: a tool call is a few dozen tokens
    and an essay is not. Checked against fourteen probes at 48, 96 and 1024, and
    the decisions are identical at all three, so this is a latency fix and not a
    behaviour change wearing one. The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
    [memory_tools.py, voice_server.py]
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2026-09-16 Move Alfred onto the MI50 and cut voice latency roughly in half
    The 2080 Super is out and a Radeon Instinct MI50 32GB is in; Ollama runs it
    through its Vulkan backend and the GTX 1060 is left to Whisper.
    Model: gemma4:26b-a4b-it-q8_0 replaces qwen3.5:9b. With Alfred's real prompt
    it reaches a first sentence in 0.43s against 1.77s and scores 75/78 on
    character_eval against 67/78. The Qwen 3.x line re-reads the whole persona
    every turn; gemma reuses the cached prefix.
    Latency, silence to first sound, measured end to end on the box:
    plain 1.5s -> 1.4s, decider turns 4.2s -> 1.9s, memory lookups 4.5s -> 2.2s,
    web answers 7.1s -> 3.8s. On the laptop, early transcription and WASAPI
    output take r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
    [alfred.py, memory_tools.py, test_listen.py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]
2026-09-16 Organize the project into folders and rewrite the README
    brain/ holds what runs on the server, client/ what runs on the laptop,
    persona/ the character, scripts/ the launch scripts, voice-training/ how the
    voice was made, tests/, requirements/, and ops/ with the server setup that
    until now existed only on the box: the MI50 fan curve, the idle-only nightly
    reboot, the boot-time model preload and the Ollama settings, each explained.
    Code finds the persona, models and venvs from the project root instead of its
    own directory, the client starts services from scripts/, and the tests put
    brain/ or client/ on the path. Everything deployed to Linux is checked out
    with LF endings.
    The old README, whi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
    [alfred.py, memory.py, memory_tools.py]
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2026-09-16 Answer weather from a live forecast and take corrections seriously
    Weather questions and their follow-ups now go to Open-Meteo instead of
    web search, which had said 78 on a 92-degree afternoon. They also skip the
    tool decider, so they answer faster than other looked-up turns.
    The spoken-delivery rule no longer assumes a correction was misheard:
    he answers the correction or says where his figure came from, and only
    says he did not catch it when the words make no sense. The rule now lives
    in alfred.py so character_eval tests the same wording the voice server
    uses, with new fixed-history correction probes (87/87 clean).
    [alfred.py, test_weather.py, voice_server.py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]
2026-09-16 Send almost every turn to the tool decider
    The word gate in front of the decider only let through questions with
    known openers, so "who's going to win", "how old is" and "hey did the
    bears win" were answered from recall instead of searched. Measured with
    the new routing_eval.py: the decider routed every turn it saw correctly,
    and all misses were the gate. It now skips only plain conversation
    (thanks, greetings, jokes, opinions), which costs about 0.15s on other
    chat turns. Routing went from 36/46 to 66/66, including 20 phrasings
    that were not used to tune it.
    [memory_tools.py]
2026-09-16 Play YouTube audio through Alfred's speaker
    "Play …" searches YouTube, announces the title in a fixed line and streams
    the audio to the client; "find videos of …" reads out the top results for
    "play the second one" or "next". A resident media service on the box
    (brain/media_server.py, its own yt-dlp + PyAV venv) searches and decodes to
    raw PCM, so the client only plays it, as a Pi Zero will later.
    On the laptop, client/music.py plays the stream, ducks it under his voice,
    and handles pause, resume, stop and volume locally. While music plays,
    listen.py cuts audio into 3s windows and only acts on turns that start with
    his name, so lyrics are never answered. Measured end to end: music start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
    [media.py, media_server.py, test_media.py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]
2026-09-16 Answer sports and news from live feeds
    Two new decider tools. get_sports reads ESPN's scoreboard JSON: a team's
    live game, last result and next fixture, a league's current slate, or the
    next UFC cards and F1 races. get_news reads Google News headlines, for a
    topic or the day's top stories. Both replace web search for questions whose
    answers change by the hour; search had answered "who's going to win copa
    libertadores" with the 2024 final.
    Routing stays at 74/74, including 8 untuned sports and news phrasings.
    End to end, answers start in 1.8-2.6s, faster than a web search.
    voice_server.py now takes ALFRED_VOICE_PORT, so scripts/voice-test-server.sh
    runs test turns on a copy beside the real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
    [memory_tools.py, news.py, sports.py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]
2026-09-16 Read live odds from Polymarket
    A get_odds decider tool searches Polymarket's public Gamma API (no key)
    for who is favoured in a game or fight, election and Fed odds, and title
    futures, and phrases prices as what the market is paying, never as advice.
    Picking the right market from the search hits failed five ways while this
    was written (search order, volume, titles only, any text); what held for
    every case is the share of query words in the title and tags, then volume.
    Those cases are pinned in tests/test_markets.py. Archived, never-traded
    markets are skipped: one carried a placeholder 49% that read as a coin flip.
    Routing 85/85, including 6 untuned odds phrasings.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
    [markets.py, memory_tools.py, test_markets.py]
2026-09-16 Summarise and play The MMA Guru's take on a fight
    He posts a predictions breakdown before every UFC card and a recap after,
    chaptered by fight, and YouTube keeps timestamped auto-captions. guru.py
    finds the newest video with a section on the fighters asked about, from
    the chapters or, failing those, the densest run of their names in the
    captions, or a video whose title names them.
    "Who does the Guru pick in X" hands that section's transcript to the
    answerer, quoted and attributed; "play the Guru's breakdown of X" or
    "play that part" streams only that section. The media service gained
    /channel, /video (chapters + captions, cached) and start/end on /stream.
    X was considered for his fight-nig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
    [guru.py, media_server.py, test_guru.py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]
2026-09-17 Send Alfred's voice at 48 kHz so Windows never converts it
    His voice crackled live but the same sentences were clean when played from a
    file. Measured first: no underflows in any output mode, no clipping or
    wrap-around in the audio, and the voice model's own output sounded fine to
    the user in a media player. What differed was the path: the client opened
    WASAPI at 32 kHz with auto_convert on 48 kHz speakers, so Windows resampled
    every sentence with its fast converter, while the music stream (48 kHz,
    no conversion) played cleanly. The server now resamples once with a proper
    filter to 48 kHz and clips the slight overshoot; the client opens at 48 kHz.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
    [voice_server.py]
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2026-09-17 Give Alfred's voice a real output buffer and report dropouts
    His voice crackled more the longer a session ran. The output stream held
    22-24ms of audio, which a warm laptop misses; WASAPI ignores "high" but
    honours a number, so it now holds 110ms (+~90ms before he speaks) and
    --buffer raises it further.
    Sentences are written in 20ms pieces so a mid-sentence underflow is
    counted and printed after the reply, instead of being blamed on the
    silence between sentences; the next crackle will say whether it was this.
    listen.py also refuses to start a second copy: the second one passed its
    health checks through the first one's tunnel, and both answered at once.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
2026-09-17 Let Alfred describe the hardware he runs on
    get_server_status now carries an inventory read once from files any user
    can read: motherboard and BIOS, CPU and RAM, each GPU and what it runs (the
    MI50 with its model, Ollama version and VBIOS; the 1060 with Whisper and its
    driver), every drive with its role (RAID 5 members holding his memory, the
    NVMe system drive, the spare), and the OS.
    "the server you run on" came back as "You're running an i7-8700", so
    the report tells him the hardware is his own and to say "I run on".
    Routing 103/103, with "i think i broke my printer again" now accepting a
    memory check.
    [machine.py, memory_tools.py]
2026-09-17 Lower the MI50 fan floor safely, and restart a stalled fan
    ops/fan/find-floor.sh walks the fan down in small steps from its floor,
    holds each for 20s, and recommends the lowest steady step plus a margin.
    Run on the box (2026-09-17) it kept 92 and saved min_pwm 98 (was 110):
    about 2,780 rpm at idle instead of 3,100. The step below stalled the fan.
    With the floor that close to stall, mi50-fan now watches the tachometer:
    two readings under 300 rpm in a row kick the fan to full speed for 3s and
    raise that run's floor by 8, logged. Sensor reads that return garbage are
    handled instead of crashing the service. Checked against a simulated fan
    that stalls below pwm 100.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
2026-09-17 Switch language by command, and log every sentence's playback
    Guessing the language per turn switched unreliably in real use. Now
    "speak Portuguese" / "fala português" and "speak English" / "volta pro
    inglês" change it and he confirms aloud. English mode is the English-only
    Whisper model as before; Portuguese mode uses the multilingual model,
    choosing Portuguese or English per turn so the command back still works.
    His voice still sounds wrong at times ("crackly", "under water"), so
    talk.py now writes every sentence's playback numbers to client/logs/
    audio.log and keeps the last 20 sentences as received in client/logs/
    clips/, to tell a bad clip from bad playback.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
    [voice_server.py, whisper_server.py]
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2026-09-17 Set the RGB memory to solid red at every boot
    OpenRGB 1.0 from its pinned release, a script that sets only DRAM devices
    to one static colour, and a oneshot unit so the colour survives reboots.
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2026-09-17 Read a YouTube channel's real uploads when asked what it posted
    Only the MMA Guru was wired in. "Latest post from Money Manzell MMA" and
    "Bedtime MMA's UFC 331 predictions" fell through to web search, which missed
    Bedtime MMA's "UFC 331 Full Card Predictions" the day it went up and read out
    titles nobody could confirm.
    get_youtube finds the channel by name through YouTube's channel search (close
    spelling wins, follower count breaks ties between namesakes), then reads its
    upload list, so every title he says is a real one. A topic like "ufc 331"
    must match its number exactly. The Guru lookup also matches a numbered card
    now, not only fight names. Routing 122/123.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
    [guru.py, media_server.py, memory_tools.py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]
2026-09-17 Stop holding the memory write lock from start-up until the first turn
    _sync_index only committed after inserting missing vectors, but its DELETE
    opens a write transaction even when it removes nothing. From voice-server
    start until the user next spoke, every other writer failed with "database is
    locked": the test-turn cleanup script died that way.
    [memory.py, test_memory.py]
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2026-09-18 Keep his owner's name out of the repository
    The name sat in forty-eight places: comments, test fixtures, the words
    Whisper is primed with, and the instructions that travel with every turn.
    It now lives beside the rest of the private wording in persona/prompts.json
    and is read through prompts.OWNER, so a public checkout carries the shape
    and not the person. Rendering the tool descriptions and the clock line
    before and after gives byte-identical text, so nothing the model reads has
    moved. Tests use a stand-in name.
    The embedding scheme label changes with it, from one that named him to
    "owner-only". The vectors behind it did not change, so the stored rows are
    relabelled in place rather than re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
    [guru.py, machine.py, memory.py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]
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2026-09-18 Keep what was said on his own machine, and nowhere else
    A conversation record belongs on his server. Two things broke that. The
    client wrote every spoken sentence, and the last twenty clips of it, into
    a folder inside the project — which sits in a synced drive, so his evenings
    were being copied to an institution's storage. And the client read his
    wording from a file it kept locally, which meant a copy of the character
    had to live on the laptop to make it speak properly.
    The playback log now defaults to per-user scratch space that syncs nowhere,
    ALFRED_CLIENT_LOGS moves it, and ops/privacy/collect-client-logs.sh sends it
    to the array and deletes the local copy once it has checked the copy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
    [voice_server.py]
2026-09-23 Let a subject be kept out entirely, not only its wording
    The scan already refused a push carrying the private wording, names and places.
    Some subjects are meant to leave no trace at all, including their name, so it
    now also reads topics.local.txt from the persona directory: one subject per
    line, matched whole and with no length floor, since the token readers drop
    anything under four characters and a short name is exactly what would slip.
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2026-09-23 Let him be typed to, not only spoken to
    client/chat.py is a terminal client: the same /chat turn as a spoken one,
    sent with "voice": false so the server skips synthesis and streams text
    frames only. Holding lines arrive as status frames, and a reply given as
    written (a list) is flagged so it prints one sentence to a line. Standard
    library only, and it tunnels its own free local port, so it runs beside
    the voice client.
    The launcher now takes its script and window title from BuildInfo, and
    build.ps1 makes both Alfred.exe and Alfred Text.exe from the one source.
    [test_chat.py, voice_server.py]
2026-09-24 Play from Spotify, asking which service when none is named
    Spotify is steered through its Web API and plays in the owner's own app;
    pause, skip, volume and ducking while he talks go through the voice server.
    Sign-in is a one-time PKCE flow run on the server over an ssh tunnel.
    [media.py, spotify.py, test_media.py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]
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2026-09-24 Stop talking when his name is said over a reply
    While a reply plays, the client keeps listening in short windows for the wake
    word only. Hearing it cuts the voice mid-sentence and drops the rest; anything
    said after the name becomes the next prompt, and "stop" and the like end it.
    [test_talk.py]
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2026-09-24 Read the voice EQ from a settings file, off unless it says otherwise
    Live, the strong treble lift brought the voice's own clicks up with it and it
    sounded crackly. The chain now comes from a small JSON file, re-read when it
    changes, so the tone can be tuned while he listens without a restart.
    [test_voice_eq.py, voice_eq.py, voice_server.py]
2026-09-25 Clean the distilled voice's training audio before training on it
    The RVC teacher clicks about seven times a second and is dull above 1 kHz, and
    no RVC setting changed that. clean_dataset.py patches each click with a cubic
    curve (threshold calibrated against the stock voice) and then corrects the tone,
    so the new voice learns clean audio. The training script takes a dataset,
    output folder and epoch count, so it can train beside the live voice.
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2026-09-25 Archive Alfred mechanical and PCB CAD revisions
    [01_Plinth.STEP, 01_Plinth.STL, 01_Plinth_modules.STEP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]
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2026-09-25 Hear Portuguese with Whisper medium
    Over 84 test clips it roughly halves Portuguese word errors against small,
    for about 1.1 s a clip instead of 0.45 s. English mode is unchanged.
    [whisper_server.py]

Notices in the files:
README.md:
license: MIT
